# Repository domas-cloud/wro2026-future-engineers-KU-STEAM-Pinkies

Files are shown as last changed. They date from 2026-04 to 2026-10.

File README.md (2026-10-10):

# KU STEAM Pinkies: WRO 2026 Future Engineers

We are **KU STEAM Pinkies** from Klaipėda University STEAM Centre. For WRO 2026 Future Engineers, we built a compact rear-wheel-drive, front-wheel-steer robot with an ESP32, a BNO085 heading sensor, three VL53L1X distance sensors and Pixy2 vision.

We gave each subsystem one job. If hardware added wiring, latency or failure points without giving us useful information, we left it out.

## Team

- **Domas Lukas (left)**
- **Jonas Danisevičius(right)**
- **Marius Plečkaitis(center)**

<p align="center">
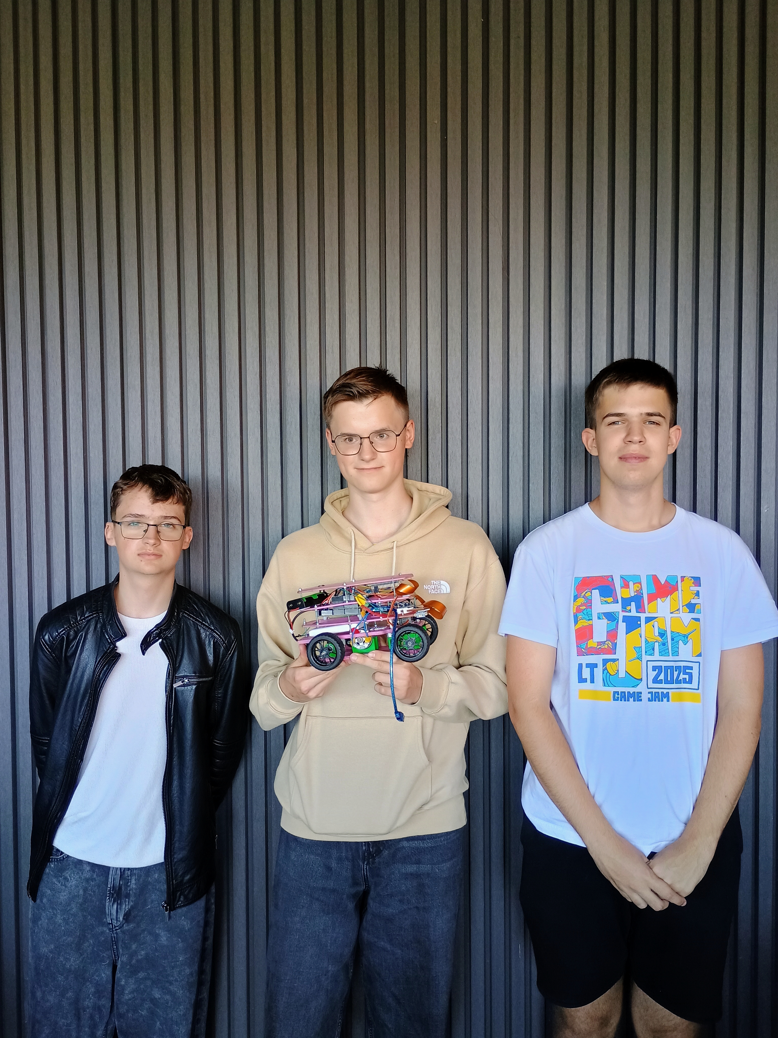
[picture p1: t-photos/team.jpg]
KU STEAM Pinkies team
  
</p>

## Competition videos

- **Open Challenge:** https://youtu.be/wYDWJLPF3cQ
- **Obstacle Challenge:** https://youtu.be/kq5EeDzJqs0

## Contents

- [Final robot](#final-robot)
- [Mechanical design](#1-mechanical-design)
- [Electronics, power and sensors](#2-electronics-power-and-sensors)
- [Software architecture](#3-software-architecture)
- [Engineering decisions and system development](#4-engineering-decisions-and-system-development)
- [Testing and tuning](#5-testing-and-tuning)
- [Robot evolution](#6-robot-evolution)
- [Bill of materials and sourcing](#7-bill-of-materials-and-sourcing)
- [Rebuilding the robot](#8-rebuilding-the-robot)
- [Repository layout](#9-repository-layout)
- [Versioning and verification record](#10-versioning-and-verification-record)
---

# Final robot

The final competition robot has a **black custom PCB and white rear wheels**.

<table>
<tr>
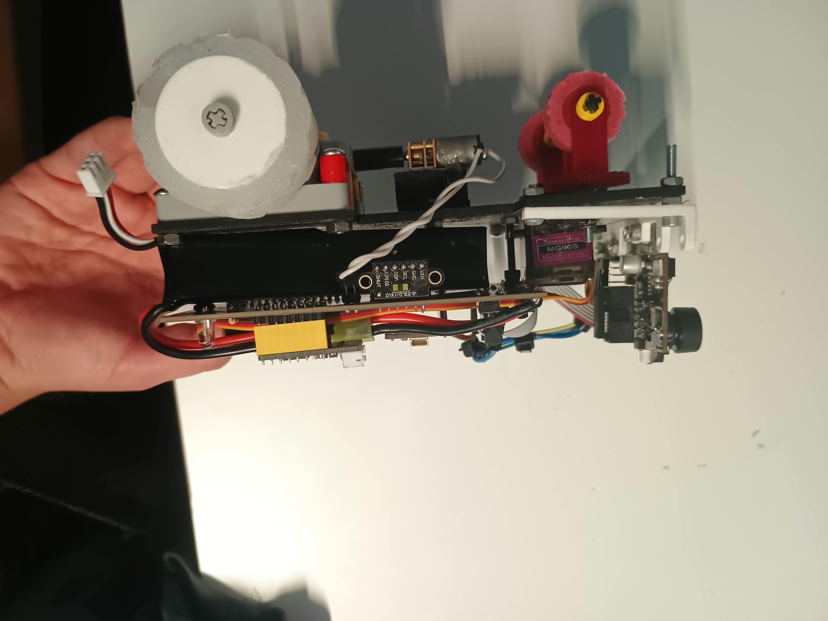
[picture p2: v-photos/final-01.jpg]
<td align="center"><br><b>Final robot, right side</b></td>
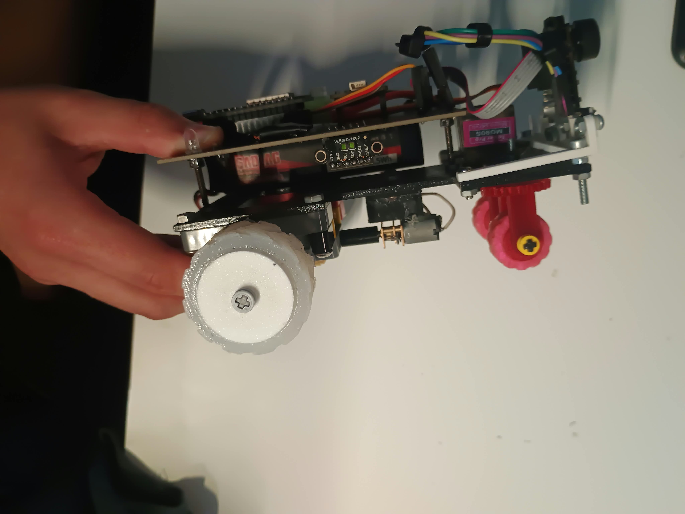
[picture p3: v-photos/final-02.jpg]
<td align="center"><br><b>Final robot, left side</b></td>
</tr>
<tr>
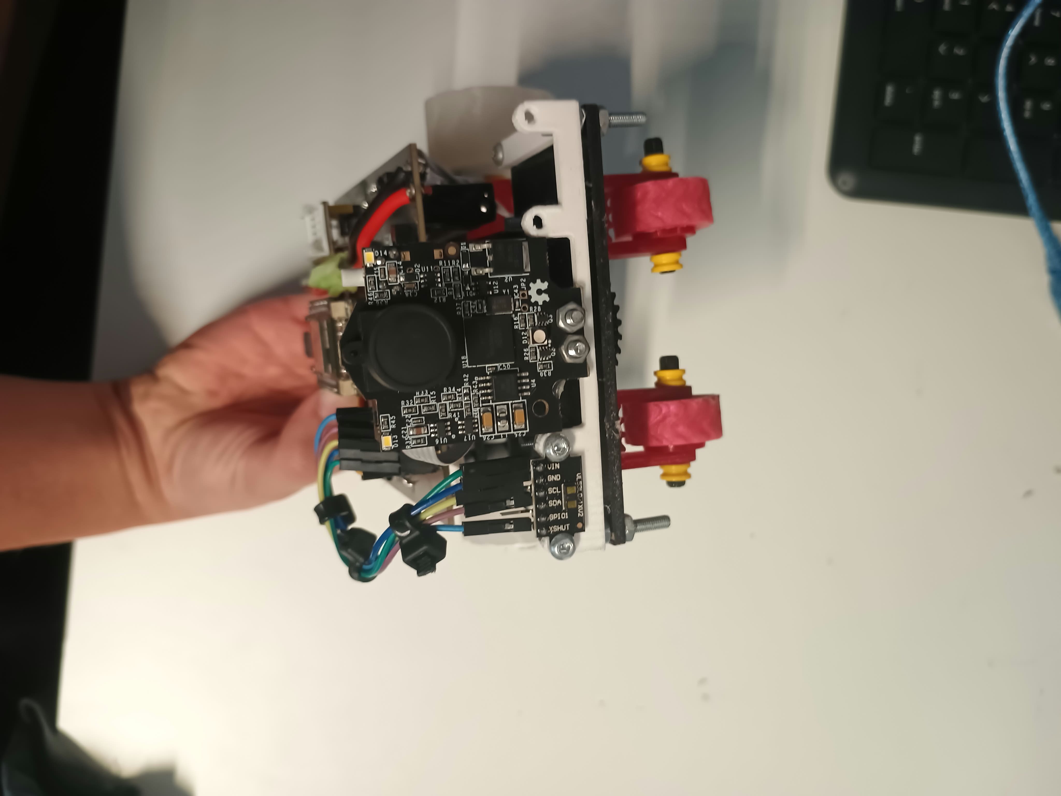
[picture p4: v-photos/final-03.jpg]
<td align="center"><br><b>Final robot, front</b></td>
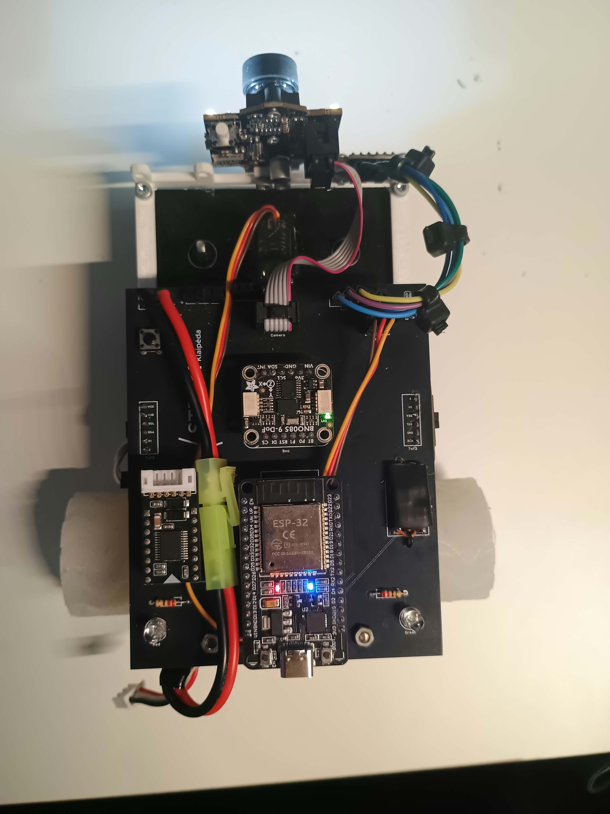
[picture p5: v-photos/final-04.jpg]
<td align="center"><br><b>Final robot, top</b></td>
</tr>
<tr>
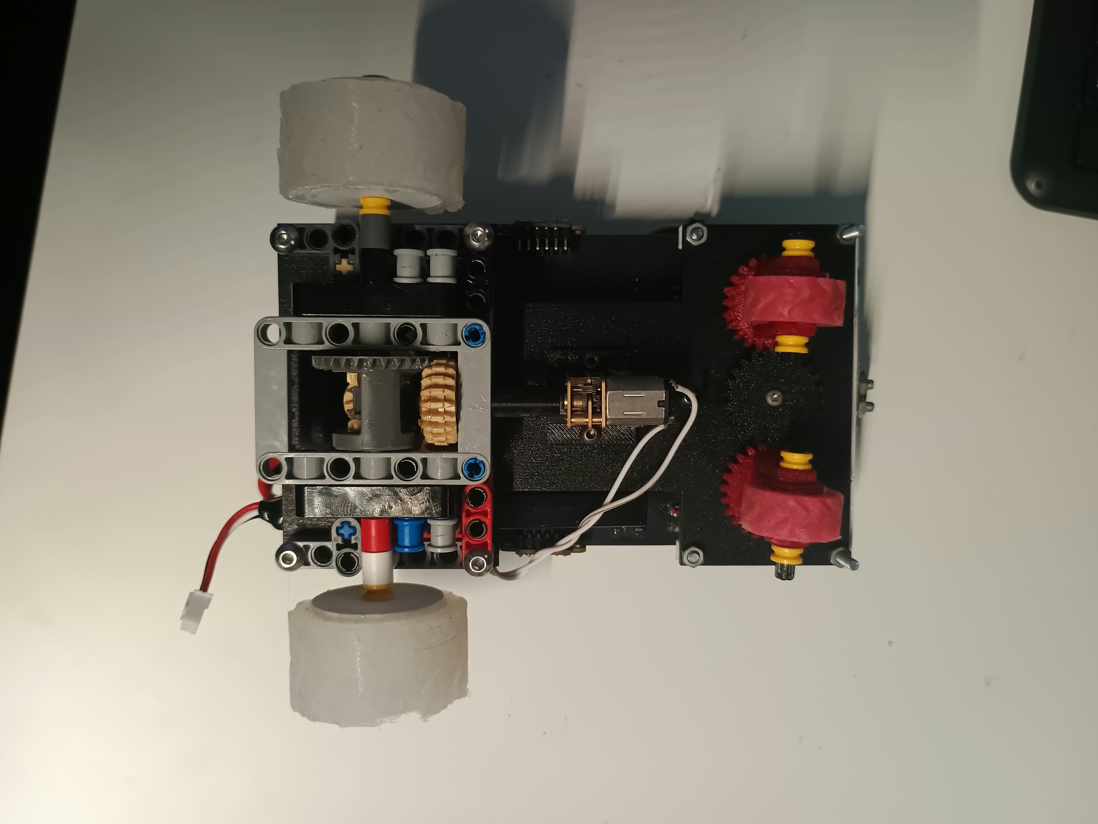
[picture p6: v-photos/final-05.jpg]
<td align="center" colspan="2"><br><b>Final robot, bottom</b></td>
</tr>
</table>

| Subsystem | Final version |
|---|---|
| Controller | ESP32-WROOM-32, 30-pin DevKit V1 form factor |
| Heading | BNO085 |
| Range sensing | 3 × VL53L1X, Long mode |
| Vision | Pixy2 / Pixy2.1 |
| Drive | rear-wheel drive |
| Motor | N20, 6 V, nominal 600 rpm |
| Transmission | LEGO-compatible gearing + LEGO differential |
| Steering | front-wheel steering, positional MG90S |
| Battery | 2S LiPo, 7.4 V, 2500 mAh, 30C |
| 5 V regulator | Matek Micro BEC 6S, 6–30 V input, 5 V/9 V adjustable, used at 5 V |
| Electronics | custom PCB |
| Mass | 332.4 g |
| Approx. overall size | 165 × 145 × 70 mm |

---

# 1. Mechanical design

## 1.1 Layout

We chose **rear-wheel drive** and **front-wheel steering**. That leaves the rear axle to provide traction and the front mechanism to steer. The layout also simplified the control model and left room in the centre of the chassis for the battery, PCB and sensors.

We kept the car compact to leave more room around corners and obstacles and reduce the steering correction needed after a turn.

## 1.2 Drivetrain

```text
N20 geared motor
      ↓
shaft adapter
      ↓
LEGO-compatible gear stage
      ↓
LEGO differential
      ↓
rear wheels
```

The nominal motor speed is 600 rpm. With the final effective reduction of about 1.50:1:

```text
wheel_rpm = 600 / 1.50 = 400 rpm
wheel circumference = π × 0.054 = 0.1696 m
ideal geometric speed = 400 × 0.1696 / 60 ≈ 1.13 m/s
```

The **0.08 N·m motor-torque value comes from the official motor specification**. The **80% drivetrain efficiency is an engineering assumption** used for the design calculation rather than a measured efficiency value:

```text
wheel torque ≈ 0.08 × 1.50 × 0.80 = 0.096 N·m
tractive force ≈ 0.096 / 0.027 ≈ 3.6 N
```

The drivetrain model was used to select the final gearing before integration. We balanced wheel speed against the torque reserve needed for acceleration, steering drag and repeated corner exits. More reduction increases wheel torque but lowers lap speed, while less reduction increases speed at the cost of control margin. The final 1.50:1 ratio gives a compact drivetrain with enough calculated tractive force for the 332.4 g vehicle while keeping the target wheel speed within the controller's useful operating range.

The N20 motor was selected because its compact geared form factor fits the rear-drive layout, aligns cleanly with the LEGO-compatible transmission and provides the required combination of speed and torque without adding another transmission stage.

## 1.3 Differential iteration

<table>
<tr><td align="center"><b>Earlier metal differential</b></td><td align="center"><b>Final LEGO differential</b></td></tr>
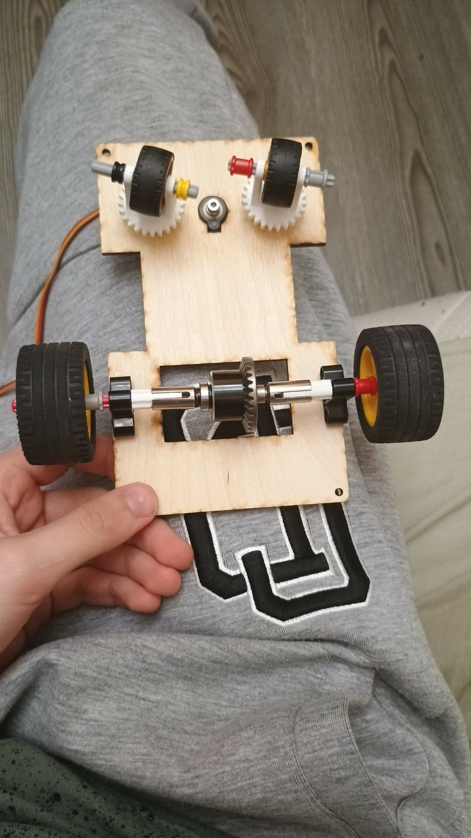
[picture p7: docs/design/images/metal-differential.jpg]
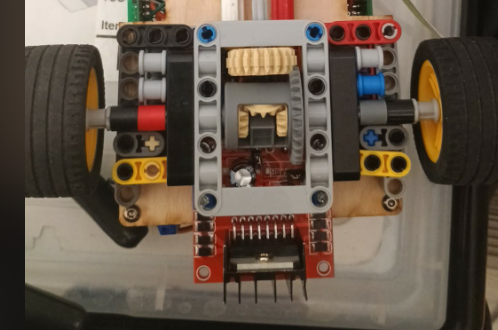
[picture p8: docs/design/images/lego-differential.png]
<tr><td></td><td></td></tr>
</table>

We kept the LEGO differential because it fits the rest of the LEGO-compatible axle and gearing directly, uses fewer custom couplings and is easier to replace during competition. It also allows the two rear wheels to rotate at different speeds in a corner.

## 1.4 Steering iteration

<table>
<tr><td align="center"><b>Earlier steering</b></td><td align="center"><b>Final steering</b></td></tr>
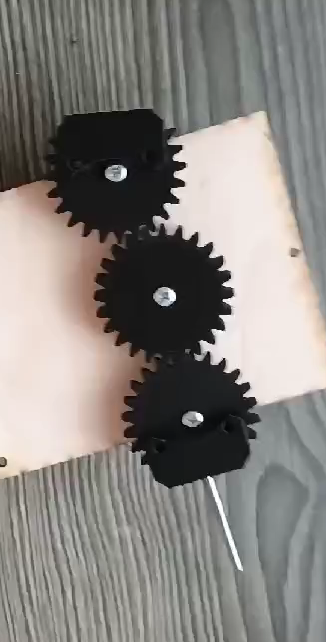
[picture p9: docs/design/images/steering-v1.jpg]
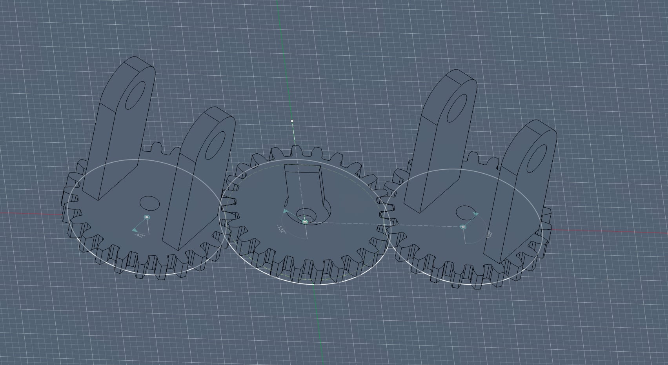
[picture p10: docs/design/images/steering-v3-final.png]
<tr><td></td><td></td></tr>
</table>

The final steering uses a positional MG90S servo. We chose this servo because the steering mechanism needs repeatable absolute positioning in a compact package, and its form factor integrates directly with the front linkage. We centre the linkage mechanically before fixing the servo horn. Firmware limits the servo command from **60° to 120°**, with **88°** as straight ahead. The final linkage is approximately **1:1 in angular movement around the centre position**, so the controller endpoints correspond approximately to **−28° and +32° of wheel steering relative to the 88° straight position**. These endpoint angles are derived from the linkage relationship and firmware commands; they are not separate protractor measurements. The limits keep the linkage inside the mechanically useful steering range and improve repeatability between runs.

The steering redesign reduced the observed space needed for a 90° turn from about **46 cm to 39 cm**, supporting the final compact linkage and steering-range choice.

## 1.5 CAD and base fabrication

The final custom parts are in `models/`:

| Current file in `models/` | Earlier name in Git history | Identification / verification note |
|---|---|---|
| `Front.stl` | unchanged | front-assembly geometry |
| `Front_wheel_gear.stl` | `Body1.stl` | formerly documented as body/structural geometry |
| `Front_wheel.stl` | `motor-shaft-spacer.stl` | formerly documented as motor-shaft spacer |
| `Rear_wheel_mold.stl` | `lego-mold-su-x.stl` | formerly documented as LEGO-interface mould/part |
| `Front_wheel_gear(1).stl` | `steering-column-housing-short.stl` | formerly documented as steering-column housing |
| `middle_gear_steering.stl` | `steering-gear-cover-disc.stl` | formerly documented as steering gear-cover disc |
| `Front_wheel_mold(1).stl` | `steering-gear-hub.stl` | formerly documented as steering-gear hub |
| `Front_wheel_mold.stl` | `steering-gear-plate.stl` | formerly documented as steering-gear plate |
| `Motor_adapter.stl` | `steering-pin-adapter.stl` | formerly documented as steering-pin adapter |
| `case.ai` | unchanged | 2D plywood/base cutting vector |

**File identity note:** These are the actual names present in the checked-in final CAD package. The previous names and descriptions come from the README and Git rename history, not from newly verified CAD assembly constraints. Some newer filenames do not match the earlier descriptions; identify installation positions by inspecting the STL geometry alongside the final robot photos. The former `ratas-su-x.stl` file was deleted and is **not** required for this revision. Do not follow older file lists or silently substitute a missing model.

`models/case.ai` is the base fabrication file. Its main rectangular path is approximately **90 × 150 mm** when imported at the original scale. That number is only a scale check; holes, slots and curves must be taken from the vector itself.

Mechanical build order:

1. cut `models/case.ai` at 1:1 scale;
2. print the STL parts without rescaling;
3. mount the N20 motor and motor-shaft interface;
4. assemble the LEGO-compatible gear stage and rear differential;
5. install the rear wheels and confirm both sides rotate freely;
6. assemble the front steering parts and MG90S;
7. centre the steering mechanically;
8. check the full range from 60° to 120° for binding;
9. mount the electronics stack and compare the result with the final photos above.

Standard LEGO Technic shafts and gears, along with ordinary fasteners, are not performance-tuned. Replace them only with parts that keep the shaft, hole and mounting geometry shown in the CAD and final assembly.

---

# 2. Electronics, power and sensors

## 2.1 Power architecture

The final battery is **2S LiPo, 7.4 V, 2500 mAh, 30C**.

```text
2S LiPo (7.4 V)
  |
  +--> custom PCB --> motor driver --> N20 motor
  |
  +--> Matek Micro BEC 6S (set to 5 V) --> 5VLINE --> ESP32 / BNO085 / VL53L1X / Pixy2 / MG90S
```

Battery energy:

```text
E = 7.4 V × 2.5 Ah = 18.5 Wh
```

### Current budget used during design

| Load | Normal | Short peak | Main concern |
|---|---:|---:|---|
| ESP32 | ~160 mA | ~240 mA | logic stability |
| BNO085 | ~15 mA | ~20 mA | heading stability |
| 3 × VL53L1X | ~75 mA total | ~120 mA total | ranging / I2C stability |
| Pixy2 | ~140 mA | ~200 mA | camera processing |
| MG90S | ~200–300 mA | ~750 mA | steering peak/stall |
| N20 motor | ~350 mA | ~1.3 A | acceleration/stall |
| whole robot | ~0.9–1.2 A | ~1.8–2.2 A coincident design peak; ~2.63 A if every listed individual peak is summed simultaneously | regulator and connector voltage drop |

The PCB netlist shows the 7.4 V battery rail feeding the **Matek Micro BEC 6S**, configured for **5 V**, whose output is the board's `5VLINE`. The regulator is specified for a **6–30 V input**, **5 V or 9 V adjustable output (5 V default)**, **1.5 A continuous load**, and **2.5 A maximum for 5 s/minute**. It also specifies over-current protection, thermal shutdown and short-circuit tolerance. Product reference: https://www.rcdalys.lt/detales/0/27234/MATEK-MICRO-BEC-6S-6-30V-5V9V-ADJUSTABLE-3PCS

The 5 V branch supplies the ESP32, BNO085, three VL53L1X modules, Pixy2 and MG90S. Using the component peak values in the table above, the listed 5 V loads sum to approximately **1.33 A**, below the BEC's **1.5 A continuous** rating. The N20 motor is supplied through the separate battery/motor-driver path, so its current is not part of the BEC load. The individual peak figures are component-level design values; the whole-robot 1.8–2.2 A figure is the expected coincident operating peak because all listed component maxima do not normally occur at exactly the same instant.

## 2.2 Custom PCB

<table>
<tr><td align="center"><b>PCB layout</b></td><td align="center"><b>PCB routing</b></td></tr>
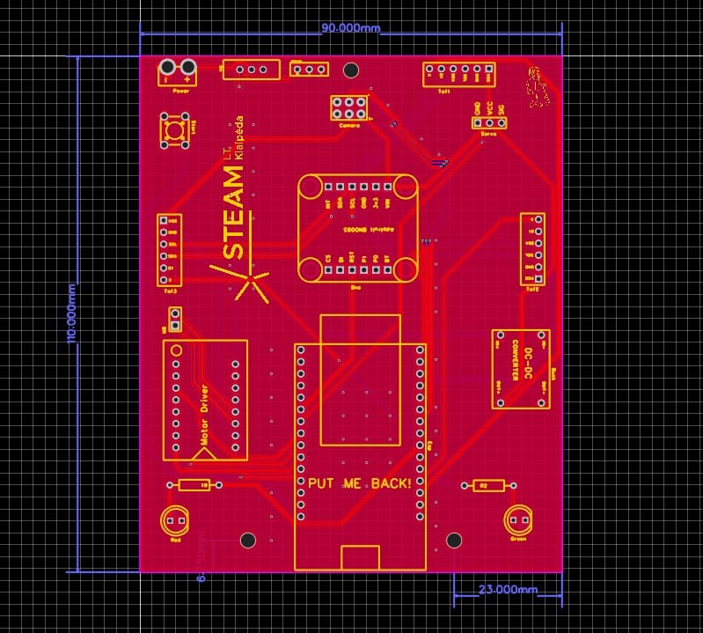
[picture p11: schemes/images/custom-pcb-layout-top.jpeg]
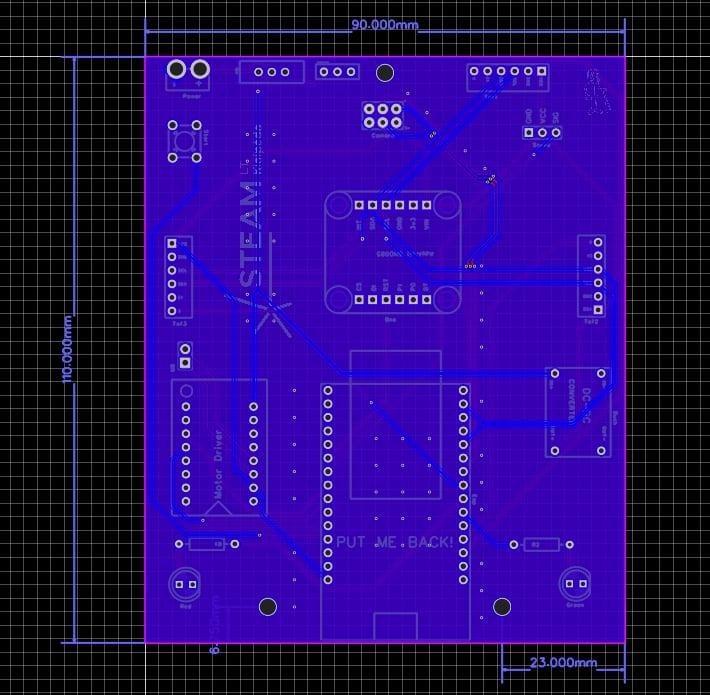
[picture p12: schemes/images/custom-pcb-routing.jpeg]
<tr><td></td><td></td></tr>
</table>

### Wiring and sensor-bus diagrams

<p align="center">
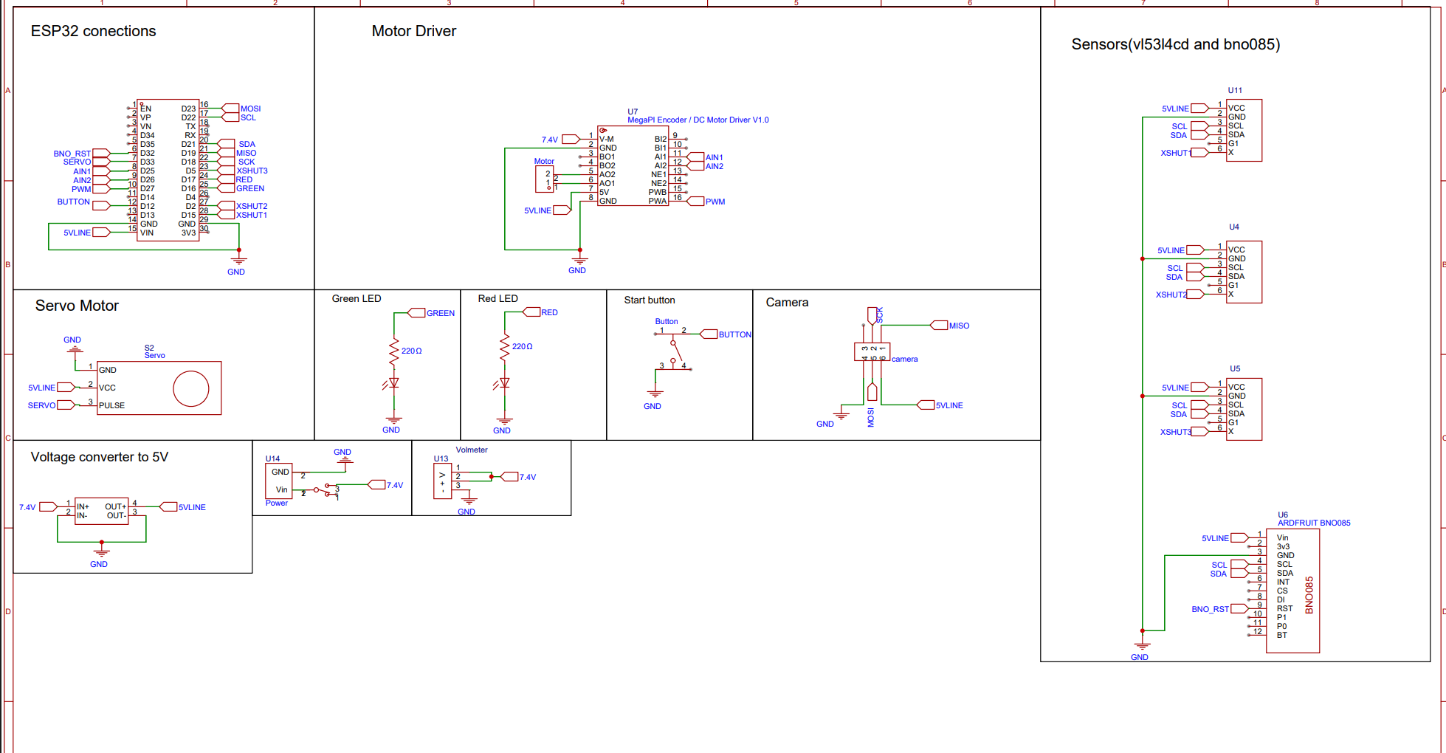
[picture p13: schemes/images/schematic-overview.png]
Robot electrical wiring and power architecture
  
</p>

<p align="center"><strong>Electrical overview.</strong> The diagram shows the battery, regulated logic supply, ESP32, motor driver, steering servo and sensor connections used on the final robot.</p>

**Sensor-bus detail (functional connection map):**

```text
ESP32 I2C SDA/SCL  ---+--- BNO085
                      +--- Front VL53L1X (XSHUT GPIO15, address 0x30)
                      +--- Left  VL53L1X (XSHUT GPIO5,  address 0x31)
                      +--- Right VL53L1X (XSHUT GPIO18, address 0x32)
ESP32 SPI (MOSI/MISO/SCK) --- Pixy2 (separate camera interface)
```

All I2C sensors share the bus; each ToF XSHUT is controlled separately to resolve the sensors' identical factory addresses. The electrical image above and the PCB files in `schemes/` are the physical wiring references. This connection map is functional rather than a substitute for the PCB netlist.

The electrical folder contains:

- `schemes/Wro_customPCBs.pdf`
- `schemes/images/schematic-overview.png`
- complete top/bottom copper, solder-mask and silkscreen Gerbers
- board outline and mechanical/document layers
- plated, non-plated and via drill files
- flying-probe test data

The Gerber and drill files are for manufacturing the final PCB revision.

## 2.3 Pin and sensor identity

| Function | ESP32 pin / bus |
|---|---|
| Start button | GPIO14 |
| Motor enable / PWM | GPIO32 |
| Motor input 1 | GPIO26 |
| Motor input 2 | GPIO25 |
| Steering servo | GPIO33 |
| Front VL53L1X XSHUT | GPIO15 |
| Left VL53L1X XSHUT | GPIO5 |
| Right VL53L1X XSHUT | GPIO18 |
| BNO085 | I2C |
| 3 × VL53L1X | shared I2C, separate XSHUT |
| Pixy2 | SPI on custom PCB (MOSI / MISO / SCK) |

All three ToF modules share the same factory I2C address. Firmware enables them one at a time and assigns each a different runtime address:

| Sensor | XSHUT | Runtime address |
|---|---:|---:|
| Front | GPIO15 | `0x30` |
| Left | GPIO5 | `0x31` |
| Right | GPIO18 | `0x32` |

## 2.4 Sensor placement and track geometry

The **front VL53L1X** faces forward on the robot **centreline**, beside the **Pixy2** camera. It measures forward clearance and helps detect a corner; Pixy2 independently reports the position of coloured obstacles. The **left and right VL53L1X** modules are installed directly in the dedicated ToF positions provided by the custom PCB, at its lateral sides, and measure the corresponding side clearances for wall correction. Their placement is therefore fixed by the checked-in PCB layout rather than by an arbitrary hand-measured mounting offset. The chassis-mounted **BNO085** provides heading, so range and orientation feedback come from separate sensors.

<table>
<tr>
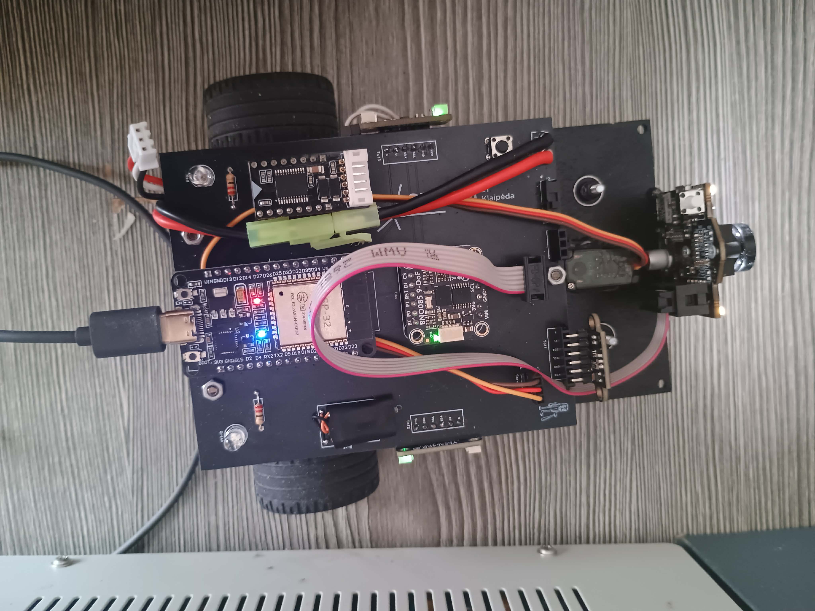
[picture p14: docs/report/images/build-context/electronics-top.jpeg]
Top view of the assembled electronics and sensor locations
<td align="center"><br><strong>Installed sensor positions.</strong> Left and right VL53L1X modules sit at the PCB side edges; the front VL53L1X is beside Pixy2.</td>
<td align="center">Dimensioned top view of the custom PCB<br><strong>PCB footprint.</strong> The drawing marks the board as 90 × 100 mm.</td>
</tr>
</table>

The robot's documented overall dimensions are approximately **165 × 145 × 70 mm**.

### Projection onto the WRO corridor

The [WRO 2026 Future Engineers rules](https://wro.hr/wp-content/uploads/2026/01/WRO-2026-Future-Engineers-Self-Driving-Cars-General-Rules.pdf) specify nominal corridor widths of **600 mm or 1000 mm** for Open Challenge, and **1000 mm** for Obstacle Challenge. The Open Challenge width may vary by ±100 mm at the International Final; Obstacle Challenge specifies ±10 mm.

For the corridor model, the **90 mm PCB dimension runs across the robot**, with the left and right ToF modules positioned at the two lateral PCB edges. The centred-reference calculation below shows how that sensor spacing relates to the nominal WRO corridor widths and to the documented 145 mm vehicle width.

| WRO section | Nominal corridor width | Side sensor centre to nearest wall, centred | Robot body side to wall, centred |
|---|---:|---:|---:|
| Open Challenge, narrow corridor | 600 mm | ≈255 mm | ≈227.5 mm |
| Open Challenge, wide corridor | 1000 mm | ≈455 mm | ≈427.5 mm |
| Obstacle Challenge | 1000 mm | ≈455 mm | ≈427.5 mm |

Calculation: `sensor-to-wall = (corridor width − 90 mm) / 2`; body clearance uses the documented 145 mm vehicle width: `(corridor width − 145 mm) / 2`. Firmware uses `ROBOT_WIDTH = 150 mm` as its rounded control model.

```text
Plan view — schematic, not to scale

600 mm corridor:
LEFT WALL │← ≈255 mm →│ ● Left ToF ── ≈90 mm ── Right ToF ● │← ≈255 mm →│ RIGHT WALL

1000 mm corridor:
LEFT WALL │← ≈455 mm →│ ● Left ToF ── ≈90 mm ── Right ToF ● │← ≈455 mm →│ RIGHT WALL

Robot layout (body width ≈145 mm):
                         FRONT / direction of travel ↑
+----------------------------------------------+
| Front VL53L1X beside Pixy2 camera            |
| Left ToF   [PCB 90 × 100 mm]   Right ToF     |
+----------------------------------------------+
```

The firmware's `TARGET_DISTANCE=300 mm` is a side-wall setpoint while the current section width is unknown; in the Obstacle Challenge build, section width is not learned, so normal wall following uses that 300 mm target. At the nominal centred geometry, this is 45 mm farther from the selected wall than the 600 mm corridor reading (≈255 mm), and 155 mm closer to the selected wall than the 1000 mm corridor reading (≈455 mm). This comparison shows why the controller's 300 mm wall target provides a practical starting point across the two Open Challenge corridor widths while leaving the final correction to the live side-distance measurements.

## 2.5 Sensor architecture changes

### MPU6050 → BNO085

The earlier MPU6050 setup showed noticeable yaw drift during repeated turns. Because heading error directly becomes steering error, we replaced it with BNO085 and used the IMU as the dedicated chassis-heading reference.

### Five range sensors → three VL53L1X + BNO085

With the BNO085 handling heading, we only needed three range measurements: front, left and right. We removed the other range modules and their wiring.

### VL53L4CD → VL53L1X Long mode

The side controller needs wall readings before the car gets close to a wall. VL53L1X Long mode provided a larger useful range, so we used it for all three distance sensors.

### Raspberry Pi camera chain → Pixy2 directly to ESP32 over SPI

The final PCB connects Pixy2 directly to the ESP32 using the SPI data and clock nets `MOSI`, `MISO` and `SCK`. This removed the Raspberry Pi processing stage and its inter-processor communication link, reducing wiring and communication stages.

## 2.6 Calibration

**ToF identity and direction**

1. Put a flat target close to the left module only and check that the left channel changes.
2. Repeat for the right module.
3. Check the front sensor against a target placed on the centreline.
4. Test several known distances and record mean reading, spread and invalid samples.
5. Make sure no wheel or chassis part clips a sensor beam.

**BNO085**

1. Point the car along a known straight reference.
2. Record yaw.
3. Rotate the chassis about 90° and confirm the expected sign/direction.
4. Cross the 0°/360° boundary to check heading wrapping.

**Pixy2**

1. Open **PixyMon** and train the colour signatures on the actual obstacle cubes used for testing.
2. Train/check each cube individually rather than relying on one generic colour sample.
3. Repeat the signature check under different lighting conditions so the stored signatures remain usable when ambient illumination changes.
4. Place a trained obstacle near image centre and confirm that Pixy2 reports the expected signature.
5. Move it left and right and verify the reported X coordinate changes in the expected direction.
6. Check that the front structure does not block the useful image area.

The camera calibration is therefore based on PixyMon's trained colour signatures rather than fixed RGB/HSV values in the ESP32 firmware.

---

# 3. Software architecture

The final firmware is in `src/` and is built with PlatformIO.

Two build environments use the same source code:

```bash
platformio run -d src -e open_challenge
platformio run -d src -e obstacle_challenge
```

- `open_challenge` uses `WRO_CHALLENGE_MODE=0`
- `obstacle_challenge` uses `WRO_CHALLENGE_MODE=1`

`src/include/CompetitionMode.h` validates the build-time value, so challenge mode is not changed by editing `main.cpp`.

Build verification is **manual**. The repository intentionally does not include GitHub Actions CI or a `scripts/` verification directory. The same two commands above are the documented reproducible build entry points.

## 3.1 Modules

| Module | Responsibility |
|---|---|
| `src/src/main.cpp` | driving behaviour and state transitions |
| `Engine` | DC motor direction and PWM |
| `Compass` | BNO085 startup and yaw |
| `Distance_Sensor` | VL53L1X startup, address assignment and ranging |
| Pixy2 interface | colour connected-component acquisition |
| `Lights` | visible robot state |
| `CompetitionMode.h` | Open/Obstacle build selection |

## 3.2 State machine

The controller follows a state machine:

```text
WAIT_FOR_START
      |
      | start button
      v
NORMAL_DRIVING
   |       |
   |       +-- corner detected --> TURNING --------+
   |                                               |
   +-- obstacle detected --> OBSTACLE_AVOIDANCE    |
                              |                     |
                              | obstacle disappears |
                              v                     |
                         OBSTACLE_RECOVERY ----------+
                              |
                              | recovery timer ends
                              v
                        NORMAL_DRIVING

12 corners / 3 laps + stable finish condition --> FINISHED
sensor-start failure ---------------------------> ERROR
```

The same control flow is shown below as a diagram for quicker review:

```mermaid
flowchart TD
    A[WAIT_FOR_START] -->|start button| B[NORMAL_DRIVING]
    B -->|corner detected| C[TURNING]
    C --> B
    B -->|obstacle detected| D[OBSTACLE_AVOIDANCE]
    D -->|obstacle no longer detected| E[OBSTACLE_RECOVERY]
    E -->|recovery interval completed| B
    B -->|12 corners / 3 laps + stable finish| F[FINISHED]
    A -->|essential sensor startup failure| G[ERROR]
```

### What each state does

- **WAIT_FOR_START** keeps the motor stopped until the team starts a run.
- **NORMAL_DRIVING** uses heading and wall control.
- **TURNING** handles a corner and updates the target heading by about 90° after the turn condition is met.
- **OBSTACLE_AVOIDANCE** gives Pixy2 steering priority while an obstacle block is present.
- **OBSTACLE_RECOVERY** keeps wall following from taking over while the car is still angled after passing an obstacle.
- **FINISHED** keeps the robot stopped after the coded three-lap finish condition. It does not execute parallel parking.
- **ERROR** stops the run if an essential sensor fails during startup.

## 3.3 Heading and wall control

Heading error is wrapped to the shortest direction:

```text
heading_error = target_heading - yaw
if heading_error > 180:  heading_error -= 360
if heading_error < -180: heading_error += 360
```

Heading error sets the base steering correction. A derivative damping term is included to reduce abrupt steering changes and improve stability as the robot converges back toward its target heading.

Wall correction uses the outside wall:

```text
wall_error = measured_outer_wall_distance - target_wall_distance
```

Clockwise runs use the left outer wall, and counter-clockwise runs use the right. The controller accepts a range reading only when its status and the combined left and right distances are plausible.

The steering command is conceptually:

```text
straight centre
+ heading correction
+ wall-distance correction
+ derivative damping
+ Pixy2 correction when avoiding an obstacle
```

Servo output is clamped to the mechanical range.

## 3.4 Corner strategy

When the front ToF detects a corner, the controller enters `TURNING`. If the driving direction is not set yet, it locks one in, steers to the turn limit and waits for the sensor to show that the car has cleared the corner. It then updates the target heading by about 90° and returns to `NORMAL_DRIVING`.

The front ToF tells the controller when to turn; BNO085 provides the heading the car should recover to.

## 3.5 Obstacle strategy

In `obstacle_challenge`, Pixy2 CCC blocks go straight to the ESP32. The controller filters detections by height so tiny or oversized blocks do not trigger steering.

Among the remaining blocks, the controller selects the block with the largest image-Y coordinate as a **camera-image proximity heuristic** (not a direct physical-distance measurement). The team trained **Pixy2 signature 1 for the green pillar** and **signature 2 for the red pillar** in PixyMon. Under the WRO rules, green must be passed on the left and red on the right. The code uses the signature-dependent horizontal image target to generate a steering correction; the sign of the resulting physical turn depends on the fitted steering mechanism and camera orientation, which must be verified on the track.

The checked-in `main.cpp` now accepts only Pixy2 **signature 1 (green)** and **signature 2 (red)** when selecting an obstacle block. Blocks bearing any other signature are discarded rather than being treated as red. This is a code-level robustness change; the physical behaviour with reflective objects, lighting variation and unexpected signatures still needs a recorded track test.

Current obstacle tuning constants:

| Parameter | Value |
|---|---:|
| Minimum block height | 8 |
| Maximum block height | 70 |
| Signature 1 — green offset | -105 |
| Signature 2 — red offset | 55 |
| Pixy steering gain | 0.32 |
| Recovery time | 450 ms |

When the obstacle disappears, the controller waits 450 ms in `OBSTACLE_RECOVERY`, then resumes wall control.

**Current competition limitation — parking:** The team's present robot does **not** implement autonomous parallel parking. The `FINISHED` state in `src/src/main.cpp` is a three-lap stop condition, **not** a parking manoeuvre. Therefore, demonstrations and performance summaries here describe driving and obstacle avoidance, not a successfully completed WRO Obstacle Challenge including parking. Parking remains an unimplemented task under the 2026 rules.

## 3.6 Controller constants

| Constant | Value |
|---|---:|
| `ROBOT_WIDTH` | 150 mm controller model |
| `TARGET_DISTANCE` | 300 mm |
| `WIDTH_THRESHOLD` | 150 mm |
| `MIN_ANGLE` | 60° |
| `MAX_ANGLE` | 120° |
| `STRAIGHT_ANGLE` | 88° |
| `Kp` | 0.09 |
| `Kg` | 0.95 |
| `Kd` | 0.05 |

## 3.7 Controller tuning and boundaries

The team iterated controller coefficients and corner behaviour during development. The final constants below are taken directly from `src/src/main.cpp`; no intermediate coefficient history is available for a numeric before/after comparison.

| Control element | Current code | Engineering purpose / check |
|---|---|---|
| Heading | `angle = Kg * heading`, `Kg = 0.95` | Bring the robot back to the BNO085 target heading; verify both driving directions |
| Wall position | `Kp = 0.09` applied to outer-wall distance error | Correct lateral displacement only when distance/geometry gates pass |
| Damping | `Kd = 0.05` applied to an error-difference term over elapsed time | Moderate abrupt steering changes; review overshoot on corner exit |
| Corner detection | Valid front ToF reading, a front-clearance threshold and combined side width ≥ 900 mm | Distinguish corner entry from normal wall following |
| Corner steering | Servo limited to 60° or 120° during the turn | Keep the command inside the chosen mechanical travel |
| Corner counting | One increment after the front-distance turn-exit condition | Track the required 12 corners over three laps |
| Normal stop | At least 12 counted corners, wall-distance error under 50 mm and heading error within 5° for 2 seconds | Avoid declaring a finish on a single instantaneous reading |

The firmware handles heading wrap across 0°/360°, stops on essential ToF/BNO085 **initialisation** failures, ignores implausible readings for specified wall-control paths and uses a 450 ms obstacle-recovery state. These are code-level mechanisms, not claims that every physical failure has been eliminated.

**Cases to test explicitly:** uncertain colour classification; an unrelated Pixy2 signature; loss of valid ToF readings during a corner; heading events unavailable after start; unexpected stopping or restarting; and return to the finish area after the twelfth corner. The corner-exit `while` loop now has an independent **5000 ms watchdog**. If it expires, the firmware stops the motor and enters `ERROR` rather than driving indefinitely. This is a conservative code fail-safe, **not a measured or validated corner duration**; verify that normal corners finish comfortably before the limit on the physical track. The `FINISHED` state remains a three-lap stop, **not** parallel parking.

## 3.8 Robustness and safeguards

The final control architecture includes several safeguards for stable competition operation:

- Separate XSHUT lines allow the three ToF sensors to receive unique runtime I2C addresses during startup.
- Essential distance and heading sensors are validated before motion begins.
- Front ToF validity is checked at corner entry, and outer-wall readings are subject to distance/geometry gates during wall correction; some other paths, including the combined side-width condition, do not separately reject all invalid readings.
- Heading error is normalised to ±180° across the 0°/360° boundary.
- Pixy2 detections are filtered by block size **and an explicit allow-list (signatures 1 and 2)** before obstacle steering is applied.
- A 5000 ms corner-exit watchdog stops the drive and enters `ERROR` if the exit condition does not occur; physical timeout validation is pending.
- Servo commands are clamped to the tested mechanical steering range.
- A dedicated recovery state smooths the transition from obstacle avoidance back to wall following.
- The documented current budget identifies the regulator's design margin; a dated under-load voltage/current log would be stronger physical verification.

---

# 4. Engineering decisions and system development

We designed around chassis size, corner clearance, steering geometry, drivetrain alignment, power stability, I2C addressing, camera view and loop latency. The robot also had to be repairable and quick to debug at a competition.

| Earlier approach | Final approach | Why we changed it |
|---|---|---|
| larger packaging | compact chassis | more clearance and simpler layout |
| metal/custom differential interfaces | LEGO differential | easier integration and repair |
| MPU6050 | BNO085 | more useful heading reference after observed drift |
| five range sensors | three VL53L1X + BNO085 | clearer sensor roles and less wiring |
| VL53L4CD side sensing | VL53L1X Long mode | larger useful wall-ranging region |
| Raspberry Pi camera chain | Pixy2 directly to ESP32 over SPI | fewer processors and communication stages |
| prototype wiring | custom PCB | repeatable and compact electrical build |
| earlier Li-ion arrangement | 2S LiPo | compact package with good transient-current reserve |
| earlier steering linkage | revised compact linkage | better centring and less binding |
| implicit behaviour flags | explicit state machine | easier to understand, test and recover between behaviours |

## Risk table

| Failure | Effect | Mitigation |
|---|---|---|
| ToF address collision | no reliable distance data | independent XSHUT + `0x30/0x31/0x32` addresses |
| bad front range | wrong corner trigger | status check and startup validation |
| bad side range | wrong wall correction | range/status/geometry filtering |
| IMU failure | no heading reference | startup check |
| heading wrap | very large false error | ±180° normalisation |
| steering over-travel | binding / heating | mechanical centring + 60°–120° clamp |
| false vision block | wrong passing path | signature 1/2 allow-list, height and image-position filtering; needs physical validation |
| stalled corner-exit reading | indefinite turn / wall collision | 5000 ms watchdog, stop motor and enter ERROR; track validation pending |
| obstacle hand-back too early | oscillation after pass | dedicated recovery state |
| power sag | reset or sensor dropout | current margin + powered load test |
| loose wiring | intermittent fault | custom PCB and fixed connectors |
| firmware/document mismatch | hard-to-reproduce robot | Git history, two fixed PlatformIO environments, manual verification workflow and the README versioning record |

---

# 5. Testing and tuning

## 5.1 Testing approach

The final robot was tuned through repeated mechanical, sensor, control and full-route testing. Consolidated results are stored in [`docs/testing/validation-summary.csv`](docs/testing/validation-summary.csv), while [`docs/testing/raw/run-template.csv`](docs/testing/raw/run-template.csv) provides a consistent format for future run-level validation.

We tuned the robot in this order:

1. free mechanical movement and steering centre;
2. BNO085 direction and heading response;
3. heading gain;
4. derivative damping;
5. wall-distance gain;
6. clockwise and counter-clockwise corners;
7. Pixy2 obstacle pass;
8. obstacle recovery;
9. repeated full-route attempts.

Saved results are in `docs/testing/validation-summary.csv`.

## 5.2 Manual verification and evidence workflow

This repository uses a manual verification workflow rather than GitHub Actions CI:

1. record the Git commit SHA for the revision being tested;
2. run `platformio run -d src -e open_challenge`;
3. run `platformio run -d src -e obstacle_challenge`;
4. perform the sensor calibration checks in section 2.6;
5. perform the final acceptance checks in section 8;
6. for each new physical run, copy `docs/testing/raw/run-template.csv` and record challenge mode, firmware SHA, battery state, changed variable, result and measured outcome;
7. update `docs/testing/validation-summary.csv` with the retained validation results.

The repository versioning and verification record is included in section 10 of this README. The complete repeatable test procedure, measurement definitions and evidence rules are in sections 5.3–5.6 **of this README**.

### Current qualitative performance estimate

The team reports **approximately 8/10 successful Open Challenge driving attempts (~80%)** and **approximately 6/10 successful Obstacle Challenge driving/avoidance attempts (~60%)** with the current robot. These are informal approximate field estimates, **not** ten individually recorded trials with a controlled layout. Their detailed pass/fail definitions, distributions across layouts and firmware SHAs have not been retained. In particular, **the obstacle estimate excludes autonomous parking**, which is not implemented. Consequently, it must not be described as a 60% success rate for completing the entire 2026 Obstacle Challenge.

The engineering development included tuning steering coefficients and corner behaviour. The current coefficient values are listed in section 3.6, and testable tuning questions are described in sections 3.7 and 5.4 of this README.

### Historical test summary and evidence provenance

The figures below reproduce the project's existing historical summary. These are **archived prior estimates, not the current 8/10 and 6/10 estimates** and not independently validated measurements. They are **not** an independently reconstructable run-by-run dataset: the original per-run logs, firmware SHA and exact field layouts for these earlier summaries were not retained. The evidence classes in `docs/testing/validation-summary.csv` distinguish team-reported comparisons, summary observations and retained five-value drift comparisons. The five-value calculations can be checked arithmetically, but the original measurement conditions cannot be independently re-created from the surviving records alone. New quantitative claims should be based on newly logged runs with firmware and layout identifiers.

| Test | Earlier | Updated/final | Notes |
|---|---:|---:|---|
| Straight drift after 2 m | 9 cm | 4 cm | prototype → final comparison, 10 runs |
| Successful 3-lap runs (archived estimate, not current) | 6/10 | 9/10 | Original per-run logs unavailable; not to be used as present success rate |
| Corner overshoot | 14 cm | 6 cm | prototype → final comparison |
| Obstacle recovery | 1.2 s | 0.6 s | prototype → final comparison |
| Matched 3 m drift mean | 10.6 cm | 4.0 cm | five retained values per version |
| Open straight | — | 5/5 | final layout |
| Obstacle slalom | — | 4/5 | final layout |
| Full practice route | — | 4/5 | final layout |
| 90° turning space | ~46 cm | ~39 cm | prototype → final comparison |

For the matched 3 m drift comparison, the retained values are:

```text
earlier: 11, 10, 12, 9, 11 cm  -> mean 10.6 cm
updated:  4,  5,  3, 4,  4 cm  -> mean  4.0 cm
```

That is a 6.6 cm reduction in the retained means, about 62%.

For future physical runs, `docs/testing/raw/run-template.csv` keeps challenge mode, firmware SHA, battery state, changed variable and measured outcome in one consistent format. The two linked YouTube videos at the top provide a visual demonstration of the final robot according to the team; they do not by themselves establish a statistically sampled success rate, nor do they establish successful parallel parking.

## 5.3 Repeatable test setup and traceability

The following procedure is for documenting **future physical testing**. It does not assert that tests were performed after the historical summary above. Estimated results must not be converted into invented per-run measurements.

Before changing firmware or tuning, save the full Git commit SHA and select the correct PlatformIO environment:
- `platformio run -d src -e open_challenge`
- `platformio run -d src -e obstacle_challenge`

Use a copy of `docs/testing/raw/run-template.csv` for each physical test series. Record the date/time, firmware SHA, mode, direction and track layout, battery voltage/state if measured, parameter intentionally changed, outcome, elapsed time, observed errors and any reset or repair. Enter `not measured` when an instrument or reliable visual measurement is unavailable rather than inventing a precision value.

The test layout should record the corridor widths (for Open Challenge), start zone, direction and the positions and signatures of relevant coloured pillars (for Obstacle Challenge). A top-view photo or sketch labelled with the run ID is useful.

## 5.4 Repeatable physical test procedures

### A. Steering and corner tuning

1. Record the deployed values of `Kp`, `Kg`, `Kd`, turn thresholds and 60°/120° steering limits.
2. Check the servo centre and both mechanical end positions with the drive motor disabled.
3. Drive a known straight segment. If measuring drift, identify the reference line, the distance travelled (2 m or 3 m), and the lateral offset at the endpoint in cm.
4. Test clockwise and counter-clockwise 90° corners with identical layout and start speed.
5. For each attempt, note whether the front ToF initiated a turn, whether it exited the turn condition, any wall contact, and any visibly excessive correction.
6. Change only one gain or threshold at a time, keeping a record of the old and new values and of the same test layout. Do not describe an improvement quantitatively unless matched measurements were retained.

### B. Pixy2 signatures and obstacle passing

The team uses signature **1 = green** and signature **2 = red**. WRO 2026 requires green to be passed on the left and red on the right.

1. In PixyMon verify each of the two trained colour signatures under the lighting used for the test.
2. Place the green and red pillar in turn at known track positions. Record each detected signature and whether the physical pass is on the required side.
3. Repeat from the two track directions where the layout permits.
4. Vary one parameter per series: target image offsets (`-105` for signature 1 and `55` for signature 2), block-height filter, steering gain (`0.32`) or recovery period (`450 ms`).
5. Note mistaken signatures, missed detections, contacts, side errors and recovery behaviour. A video link and timestamp should be attached for decisive cases.
6. Present an unrelated/untrained Pixy2 signature during a controlled test. Confirm that it is ignored and does not create an obstacle steering command; record the event and firmware SHA.

### C. Three-lap run, stopping and parking status

1. Record the firmware SHA, track layout and start configuration.
2. Attempt three full laps without touching or adjusting the vehicle after the authorised start.
3. Record laps and counted corners, final stopping behaviour, wall/pillar contacts and whether intervention was required.
4. **Current status:** autonomous parallel parking is **not implemented**. For an Obstacle Challenge driving run, score the three-lap/obstacle portion separately and record parking as `not implemented`, never `success`. If parking is added in a future firmware revision, separately record whether the parking-space boundaries remain untouched and whether the robot finishes inside and parallel. The present `FINISHED` state only implements a stop condition.
5. A success fraction is `successful independently documented runs / all independently documented attempts`. Keep failed attempts in the denominator; do not combine incompatible layouts as if they were identical.

### D. Corner-exit watchdog and failure checks

1. With the drive wheels raised and no wall contact possible, verify that a stuck front-ToF corner-exit condition cannot keep the motor running indefinitely; expected code action is motor stop and `ERROR` after 5000 ms.
2. Repeat normal clockwise and counter-clockwise corners on the actual track, recording entry-to-exit times and whether the watchdog was activated.
3. Treat the fail-safe as **implemented but not physically verified** until these tests are logged; never report test success solely because the code contains the watchdog.

## 5.5 Metric definitions

| Metric | Definition | Source |
|---|---|---|
| Straight-line drift (cm) | Lateral endpoint offset after a stated 2 m or 3 m straight | Tape/ruler and reference line |
| Turn overshoot (cm) | Maximum lateral deviation from the stated intended path after a 90° corner | Marked track / measured video |
| Obstacle pass success | Correct pass side with no disqualifying contact | Video + run sheet |
| Three-lap completion | Three complete laps and separately recorded finish behaviour | Video + run sheet |
| Obstacle recovery (s) | Time from obstacle no longer being detected to normal steering control, using a defined source | Instrumented trace / frame-by-frame video |
| Reset/timeout count | Number of controller resets or uncompleted turn conditions per run | Serial/event notes |
| Supply voltage (V) | Measured 5 V line or battery voltage and specified load state | Multimeter / logger |

Report `n`, exact metric, units, setup and spread/range with any average. When a metric cannot be measured, log the observation qualitatively and leave the numeric field blank or mark it unavailable.

## 5.6 Evidence quality and reporting

1. Source-controlled firmware SHA, raw run record, corresponding video with time markers and a documented layout.
2. Dated test notes with measured values and enough setup information to repeat.
3. Historical team summary and observations, which can illustrate development but are not equivalent to a traceable run series.

Preserve the existing `validation-summary.csv` as a historical summary. Add new physical results with their own source evidence and do not overwrite older values to make the trend look smoother.

The retained historical CSV remains linked as a numerical supporting file, while the result interpretation and the measurement protocol are fully explained in this README. A future physical test may improve the confidence in the reported estimates; documentation alone cannot supply missing measurements.

---

# 6. Robot evolution

We kept older photos to show how the design changed.

## Stage 1: earlier full vehicle

<table>
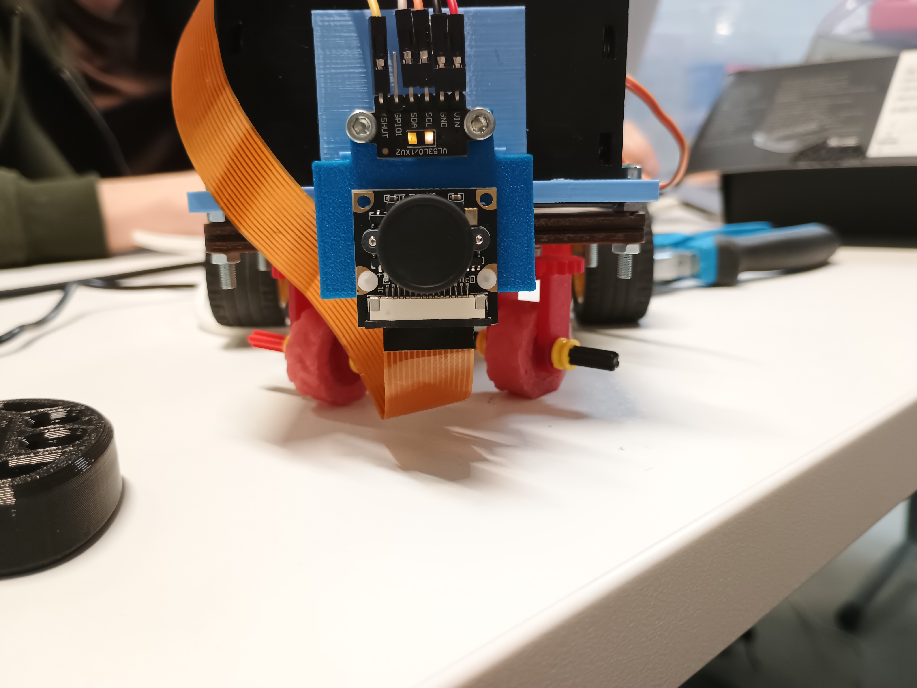
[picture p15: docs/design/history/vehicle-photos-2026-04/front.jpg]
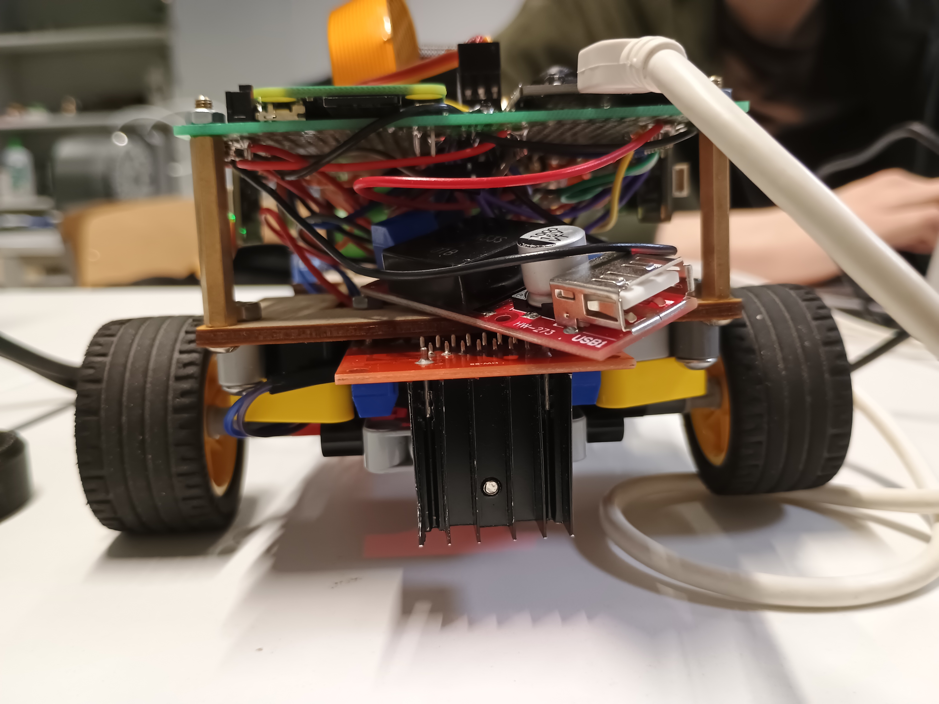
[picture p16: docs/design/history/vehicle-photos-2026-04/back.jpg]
<tr><td></td><td></td></tr>
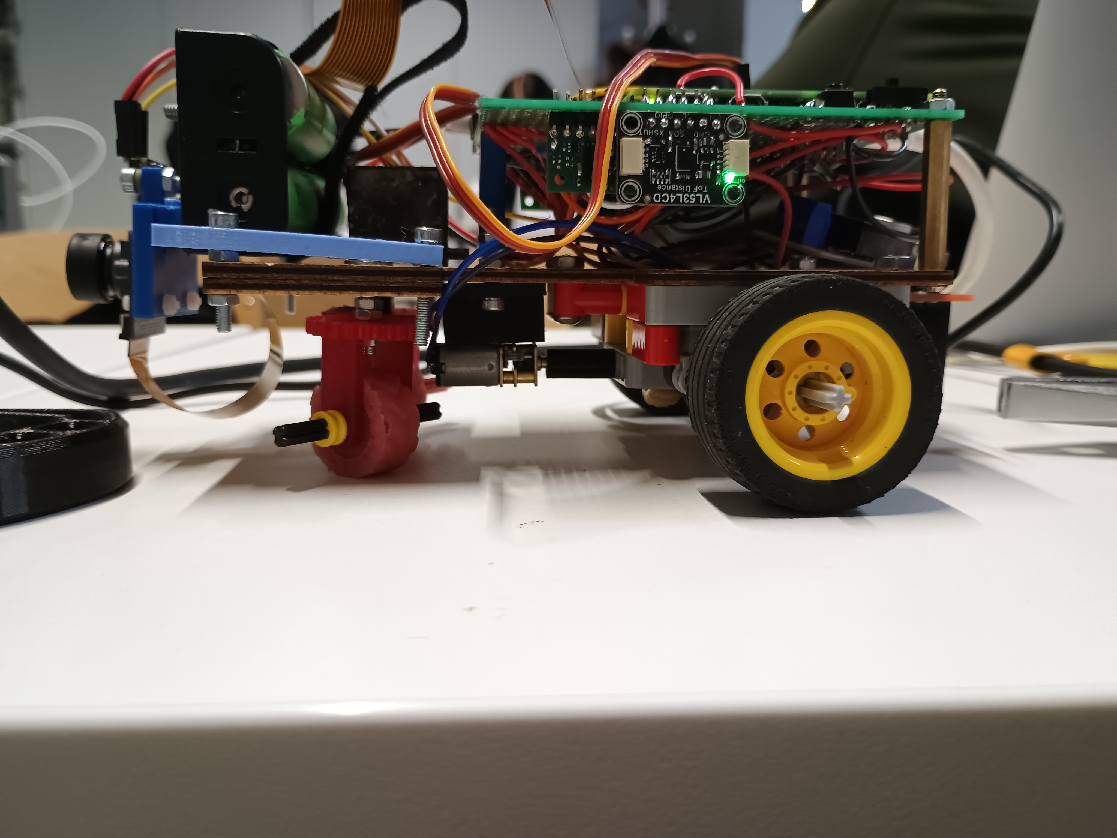
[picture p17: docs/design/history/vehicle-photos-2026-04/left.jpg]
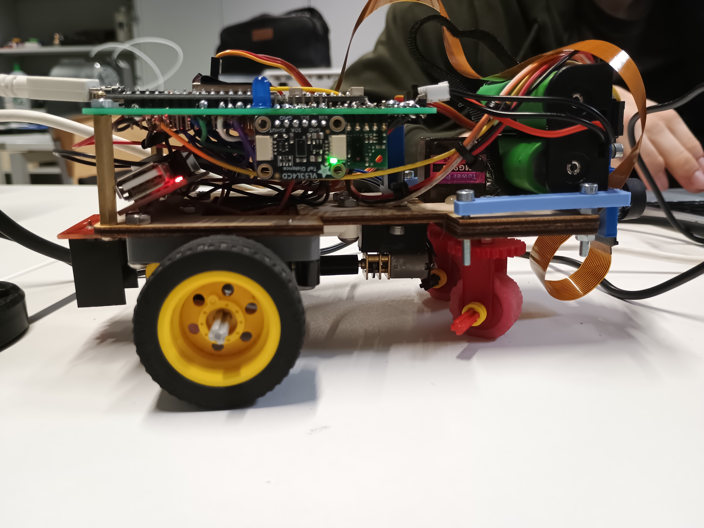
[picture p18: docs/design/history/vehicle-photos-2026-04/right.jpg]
<tr><td></td><td></td></tr>
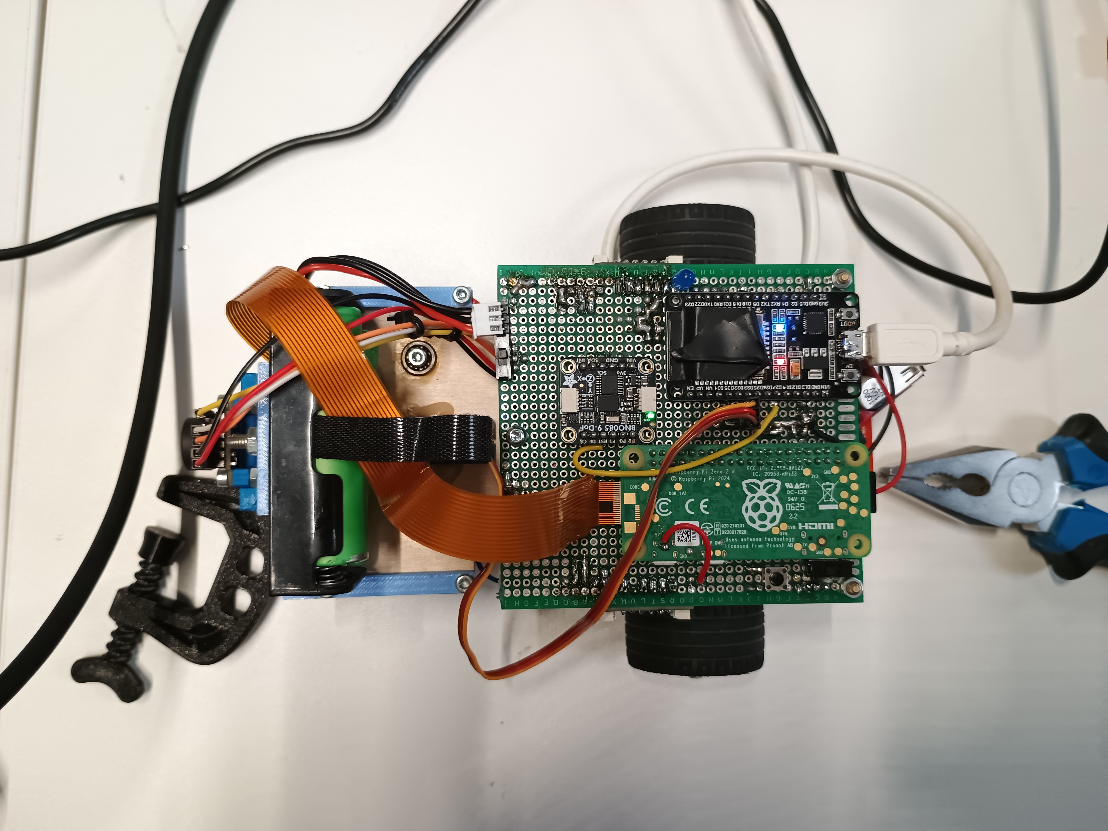
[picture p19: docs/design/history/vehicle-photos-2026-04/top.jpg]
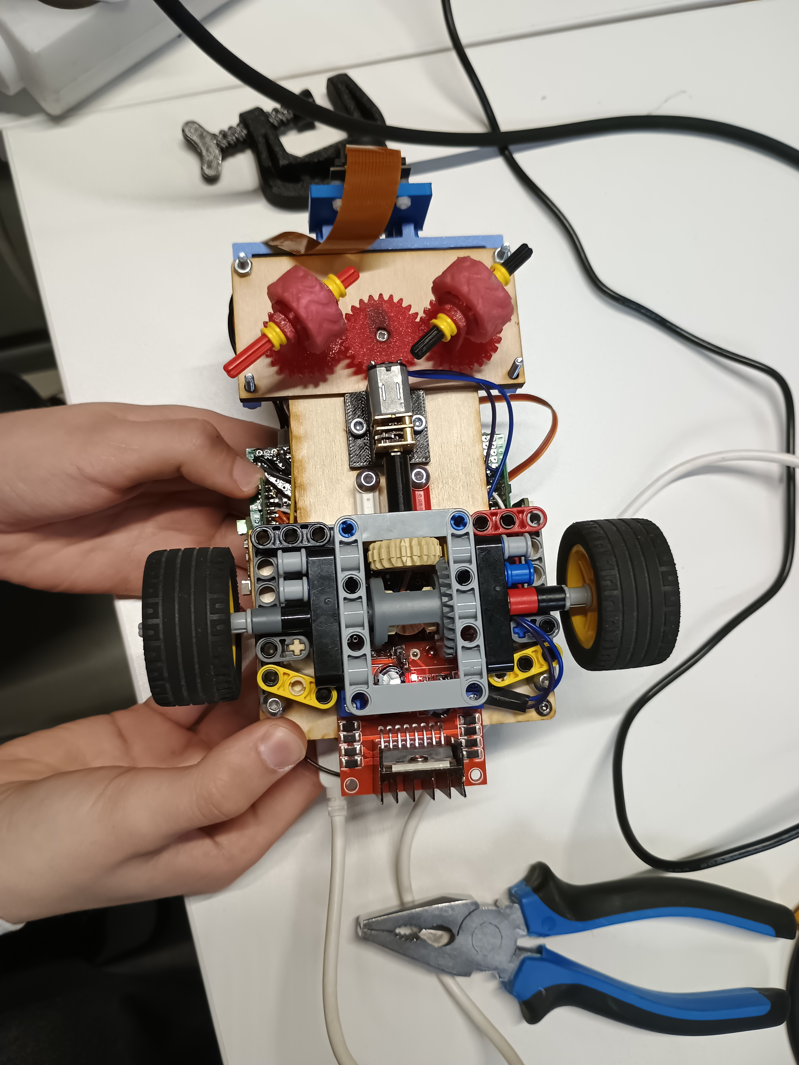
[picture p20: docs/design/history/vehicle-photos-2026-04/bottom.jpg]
<tr><td></td><td></td></tr>
</table>

This is the earlier packaging baseline. The later car is smaller and uses less hardware.

## Stage 2: differential and drivetrain

<table>
<tr><td></td><td></td></tr>
</table>

## Stage 3: steering

<table>
<tr><td></td><td></td></tr>
</table>

## Stage 4: electronics integration

<table>
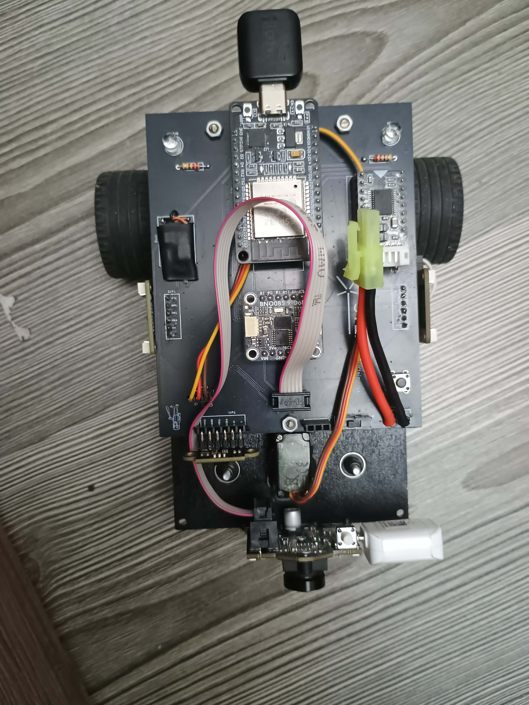
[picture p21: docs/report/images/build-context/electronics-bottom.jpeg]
<tr><td></td><td></td></tr>
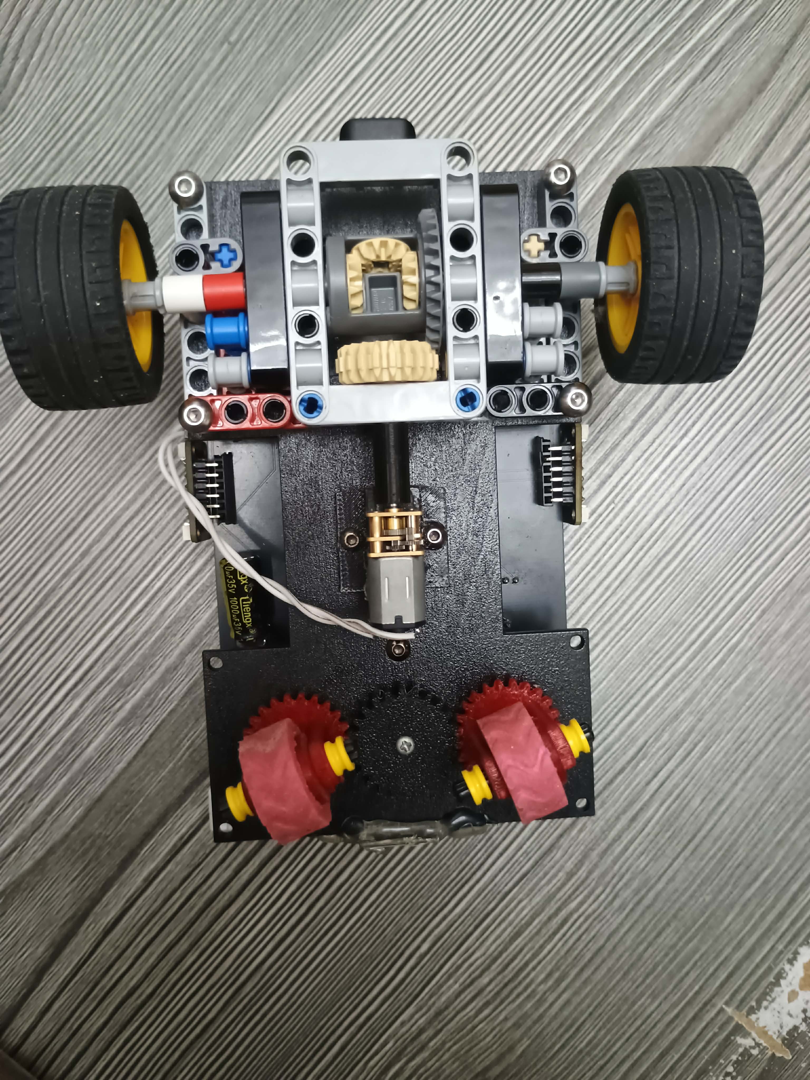
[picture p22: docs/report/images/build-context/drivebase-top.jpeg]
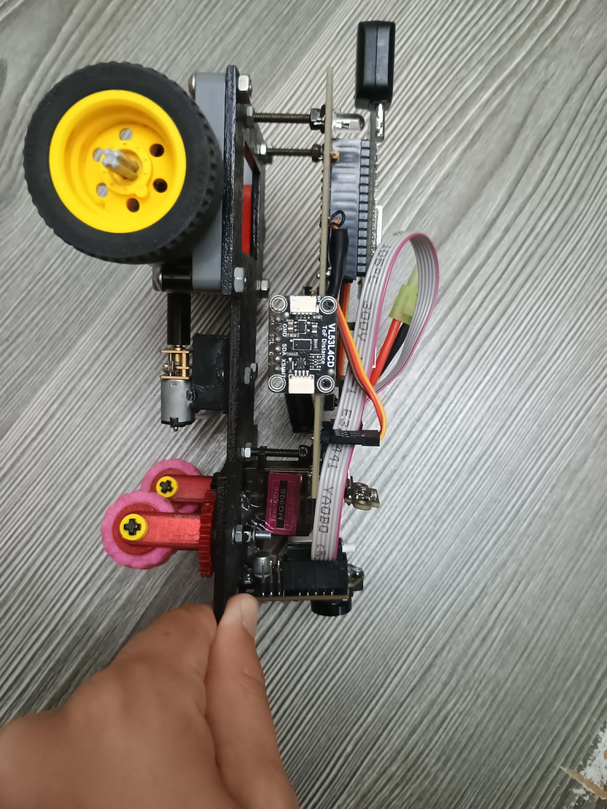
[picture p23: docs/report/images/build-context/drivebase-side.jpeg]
<tr><td></td><td></td></tr>
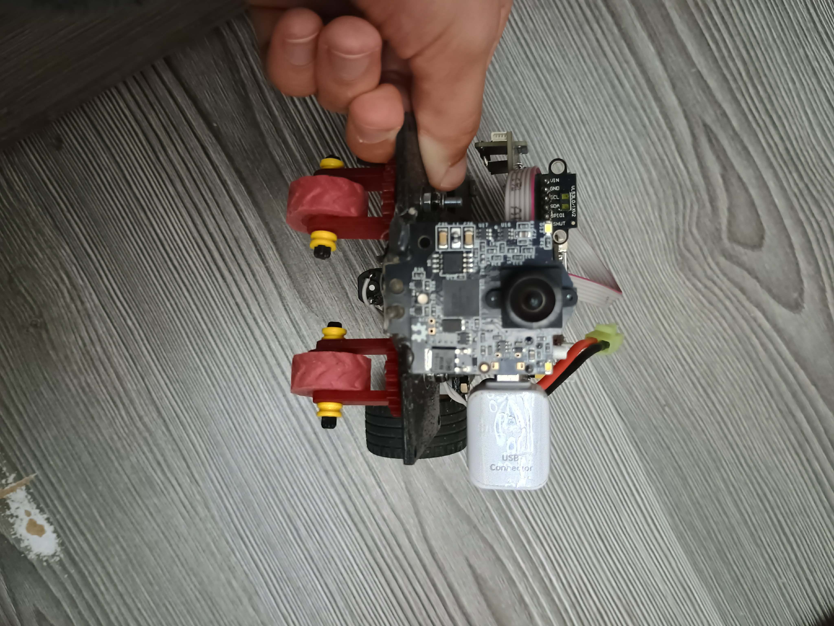
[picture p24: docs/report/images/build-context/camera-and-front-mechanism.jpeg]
<tr><td colspan="2" align="center"></td></tr>
</table>

## Stage 5: final competition robot

The five photos near the top show the final robot with the black PCB and white rear wheels.

---

# 7. Bill of materials and sourcing

The supplier links are examples. Match each part to the model, footprint and electrical or mechanical interface listed here.

| Qty | Component | Final specification | Example source | Important detail |
|---:|---|---|---|---|
| 1 | ESP32 board | ESP32-WROOM-32 DevKit V1, **30 pin** | [3DSVET EU](https://www.3dsvet.eu/izdelek/esp32-wroom32-30pinov-microusb/) | 38-pin boards do not fit the same PCB footprint |
| 1 | IMU | Adafruit BNO085, product 4754 | [Adafruit](https://www.adafruit.com/product/4754) | fixed chassis orientation |
| 3 | ToF sensor | VL53L1X on 6-pin carrier | [Pololu](https://www.pololu.com/product/3415) | the sensor itself must be VL53L1X, even if the carrier looks similar |
| 1 | Camera | Pixy2 / Pixy2.1 CMUcam5 | [RobotShop EU](https://eu.robotshop.com/products/charmed-labs-pixy-21-robot-vision-image-sensor-rbc) | direct ESP32 SPI connection through the custom PCB |
| 1 | Steering servo | TowerPro MG90S positional | [Anodas LT](https://www.anodas.lt/en/towerpro-mg90s-micro-analog-servo-with-metal-gear) | do not use 360° continuous rotation |
| 1 | Motor driver | Makeblock MegaPi Encoder/DC Motor Driver V1 | [BerryBase](https://www.berry-base.com/makeblock-megapi-encoder-dc-motor-driver-v1-2-kanaele-6-12-v-3-a-nennstrom-5-5-a-peak) | brushed DC output used |
| 1 | Drive motor | N20, 6 V, nominal 600 rpm, 3 mm D-shaft class | [HESTORE](https://www.hestore.eu/prod_10042830.html) | check shaft length before ordering |
| 1 | Battery | 2S LiPo, 7.4 V, 2500 mAh, 30C | RC supplier | must fit final packaging |
| 1 | 5 V regulator | Matek Micro BEC 6S, 6–30 V input, 5 V/9 V adjustable | [RCdalys](https://www.rcdalys.lt/detales/0/27234/MATEK-MICRO-BEC-6S-6-30V-5V9V-ADJUSTABLE-3PCS) | set to 5 V; 1.5 A continuous, 2.5 A max for 5 s/min |
| 1 | PCB | KU STEAM Pinkies final board | `schemes/` Gerbers | manufacture from the checked-in package |
| 1 | Rear differential | LEGO-compatible differential | LEGO/Technic source | geometry must match final drivetrain |
| 2 | Rear wheels | final white custom wheel geometry | `models/` | use final wheel CAD/material |
| 2 | Front wheel/steering assemblies | final printed/LEGO-compatible geometry | `models/` | do not scale STL files |
| 1 | Plywood base | final cut vector | `models/case.ai` | import at 1:1 scale |

### Replacement rules

- ESP32 replacements must keep the same 30-pin footprint and required GPIOs.
- ToF replacements must use VL53L1X and expose XSHUT.
- Servo must be positional, not continuous rotation.
- The 5 V regulator must meet the final Matek Micro BEC 6S electrical role: 2S-compatible input and enough continuous current for the documented 5 V load.
- N20 replacements must match voltage, speed class and shaft geometry.
- Mechanical substitutions must preserve axle, hole and wheel geometry.
- Treat any change to the pinout, sensor type, wheel size, steering geometry or camera interface as a new robot revision, and retest the robot.

---

# 8. Rebuilding the robot

Use the CAD files and steps below to rebuild the robot. Use the photos as visual references, not for measuring dimensions.

## Mechanics

1. Cut the base from `models/case.ai`.
2. Print the final STLs from `models/` without scaling.
3. Assemble the rear motor, gear stage, differential and wheels.
4. Assemble the front steering parts and MG90S.
5. Centre the linkage and verify the command range from 60° to 120°.

## Electronics

1. Manufacture the PCB from the `schemes/` Gerber/drill package.
2. Install the 30-pin ESP32 board.
3. Connect BNO085 and the three VL53L1X modules to I2C.
4. Connect XSHUT to GPIO15 / GPIO5 / GPIO18 for front / left / right.
5. Connect MG90S to GPIO33.
6. Connect the motor driver to GPIO26, GPIO25 and GPIO32.
7. Connect Pixy2 to the final board's SPI camera connector; the PCB routes `MOSI`, `MISO`, `SCK`, 5 V and GND to the camera header.
8. Check ground and supply polarity before applying motor power.

## Firmware

```bash
platformio run -d src -e open_challenge
platformio run -d src -e obstacle_challenge
```

Upload the build for the required challenge, then run the calibration checks in section 2.6.

## Final acceptance checks

- base and printed parts match the final CAD revision;
- drivetrain turns freely;
- steering is centred and does not bind;
- front/left/right ToF identities match `0x30/0x31/0x32`;
- BNO085 heading direction is correct;
- Pixy2 image direction matches steering logic;
- ESP32 does not reset during hard steering and acceleration;
- only trained Pixy2 signatures 1/2 influence obstacle steering (regression test still required);
- the corner-exit watchdog ends a stuck turn without ongoing motor power (physical validation still required);
- both PlatformIO environments compile;
- Open Challenge straight/corner control runs without manual input;
- Obstacle Challenge recognises the trained signatures, passes and recovers to normal driving;
- parallel parking is **not yet implemented**; do not record the entire 2026 Obstacle Challenge as complete.

---

# 9. Repository layout

```text
README.md                     project engineering journal
src/                          ESP32 PlatformIO firmware
models/                       final STL/CAD + case.ai base vector
schemes/                      schematic images, PCB PDF, Gerbers and drill files
videos/                       competition run recordings
v-photos/                     final robot photographs
t-photos/                     team photograph
docs/design/images/           drivetrain and steering development photos
docs/design/history/          earlier whole-robot photographs
docs/report/images/           build/electronics development photographs
docs/testing/                 retained validation CSV and raw-run template
```

This README is the **single engineering-journal and assessment narrative**: technical rationale, methods, results, limitations, reconstruction, testing procedures and version notes are readable here without opening another Markdown document. Source code, CAD, PCB files, CSVs, photos and videos stay in their original formats as linked supporting evidence. Build verification is manual; there is intentionally no GitHub Actions CI or `scripts/` verification directory in the current repository.

---

# 10. Versioning and verification record

This section records the competition-ready documentation state of the robot and the workflow used to keep hardware, firmware and validation evidence aligned. Git commit history provides the detailed change-by-change record, while this section identifies the current documented revision and the checks expected after material changes.

## Current competition revision

The documented competition configuration uses:

- ESP32-WROOM-32, 30-pin DevKit V1 form factor;
- BNO085 heading sensor;
- 3 × VL53L1X distance sensors in Long mode;
- Pixy2 / Pixy2.1 vision connected directly to ESP32 over SPI;
- N20 6 V motor, nominal 600 rpm;
- LEGO-compatible gearing and rear differential;
- MG90S positional steering servo;
- 2S LiPo, 7.4 V, 2500 mAh, 30C;
- custom PCB;
- approximate overall size of 165 × 145 × 70 mm;
- documented mass of 332.4 g.

The firmware is maintained as one source tree with two explicit PlatformIO environments. The currently documented Obstacle build has pillar avoidance and finish stopping, but **no autonomous parallel-parking routine**:

```bash
platformio run -d src -e open_challenge
platformio run -d src -e obstacle_challenge
```

- `open_challenge` uses `WRO_CHALLENGE_MODE=0`;
- `obstacle_challenge` uses `WRO_CHALLENGE_MODE=1`.

## Reproducibility package

The repository keeps the material needed to rebuild, inspect and validate the documented robot in version control:

- `README.md` — design reasoning, architecture, calibration, tuning, rebuild instructions and this versioning record;
- `src/` — ESP32 PlatformIO firmware;
- `models/` — final STL/CAD files and `case.ai`;
- `schemes/` — PCB documentation, Gerbers, drill files and schematic images;
- `docs/testing/validation-summary.csv` — retained validation summary;
- `docs/testing/raw/run-template.csv` — repeatable run-record format;
- `README.md` section 5 — the full test protocol, metric definitions, evidence requirements and historical result context;
- `v-photos/` — final robot photographs;
- `t-photos/` — team photograph;
- `videos/` — competition run recordings.

## Verification workflow for a material revision

When a material robot revision is made:

1. record the Git commit SHA used for the revision;
2. build both PlatformIO environments;
3. repeat the calibration checks in section 2.6;
4. repeat the final acceptance checks in section 8;
5. record new physical runs using `docs/testing/raw/run-template.csv`;
6. update `docs/testing/validation-summary.csv` from retained measurements;
7. document what changed, why it changed and which subsystem was affected.

A change to pinout, sensor type, wheel size, steering geometry, camera interface or challenge-control behaviour is treated as a new robot revision and is rechecked before its results are used as final competition evidence.

## Revision trace

The Git history provides the detailed evolution of the project. Meaningful commits cover the major documented revisions, including chassis and drivetrain development, steering redesign, sensor architecture changes, custom PCB integration, Pixy2 SPI correction, testing workflow updates and final power/sensor/calibration documentation. Together with the robot-evolution section and retained test results, this provides traceability from earlier prototypes to the current competition configuration.

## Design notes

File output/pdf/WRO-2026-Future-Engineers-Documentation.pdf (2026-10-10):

# KU STEAM Pinkies: WRO 2026 Future Engineers

We are KU STEAM Pinkies from Klaipėda University STEAM Centre. For WRO 2026 Future Engineers, we built a compact rear-wheel-drive, front-wheel-steer robot with an ESP32, a BNO085 heading sensor, three VL53L1X distance sensors and Pixy2 vision.

We gave each subsystem one job. If hardware added wiring, latency or failure points without giving us useful information, we left it out.

## Team

Domas Lukas (left)
Jonas Danisevičius(right)
Marius Plečkaitis(center)

## Competition videos

Open Challenge: https://youtu.be/wYDWJLPF3cQ Obstacle Challenge: https://youtu.be/kq5EeDzJqs0

## Contents

Final robot
Mechanical design
Electronics, power and sensors
Software architecture
Engineering decisions and system development

Testing and tuning
Robot evolution
Bill of materials and sourcing Rebuilding the robot
Repository layout
Versioning and verification record

# Final robot

The final competition robot has a black custom PCB and white rear wheels.

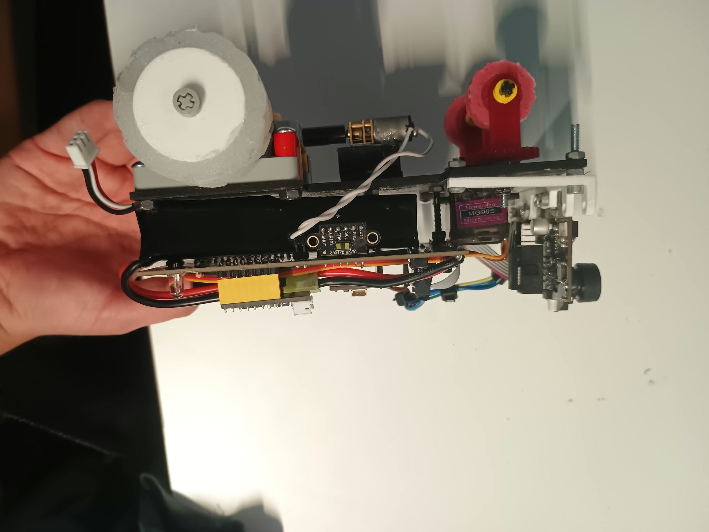
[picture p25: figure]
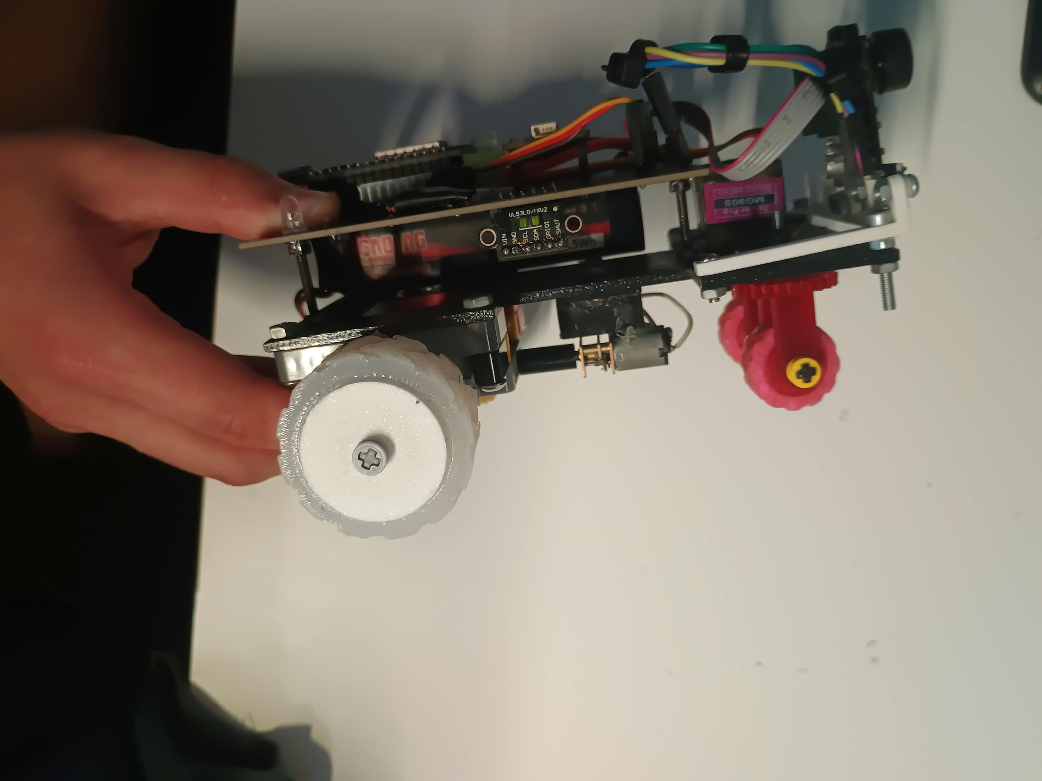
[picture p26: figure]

Final robot, right side | Final robot, left side

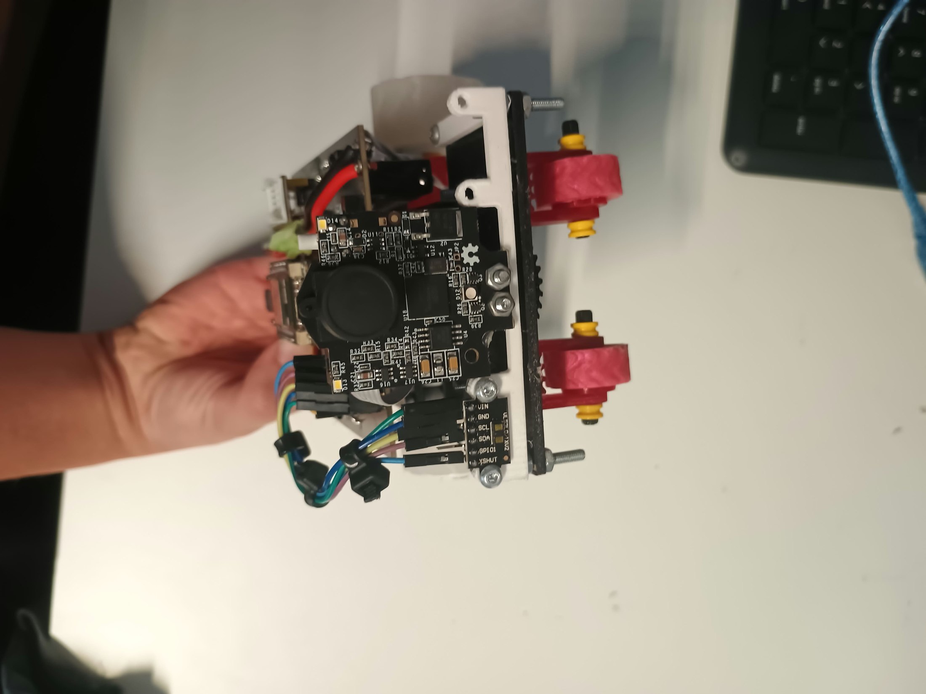
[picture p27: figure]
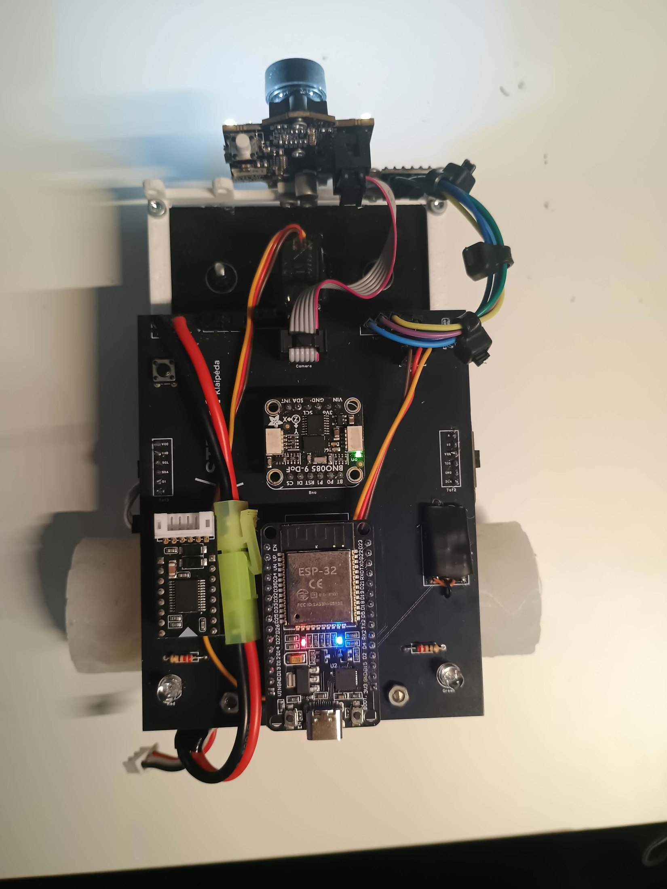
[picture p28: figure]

Final robot, front | Final robot, top

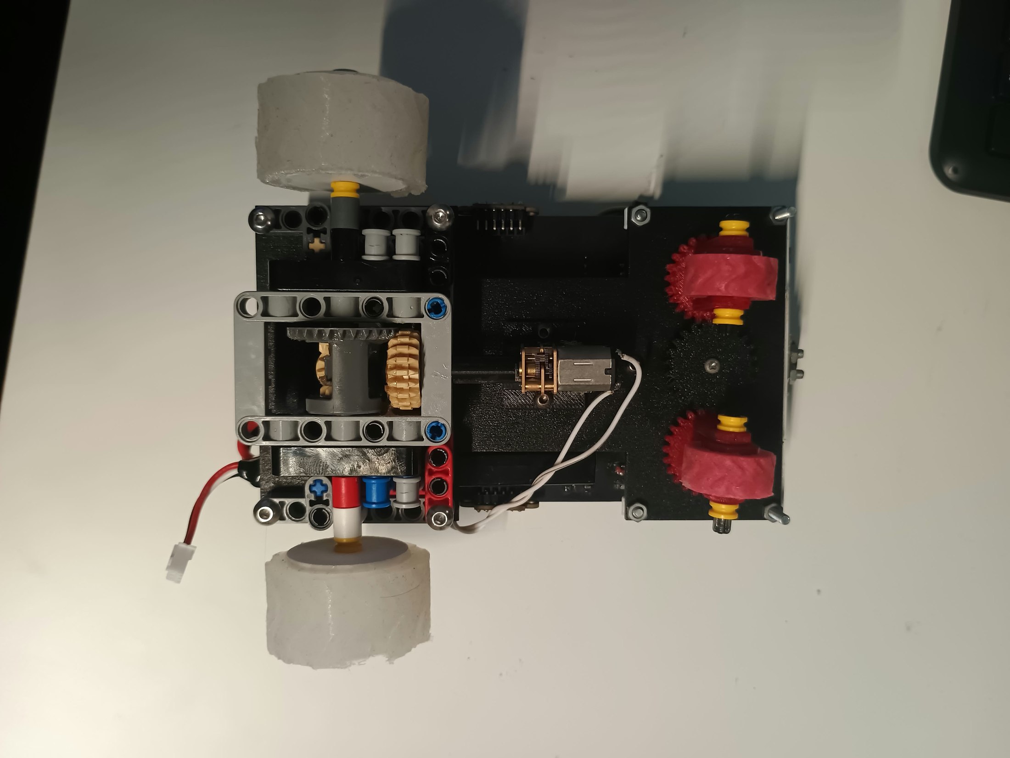
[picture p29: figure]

Final robot, bottom

Subsystem | Final version
Controller | ESP32-WROOM-32, 30-pin DevKit V1 form factor
Heading | BNO085
Range sensing | 3 × VL53L1X, Long mode
Vision | Pixy2 / Pixy2.1
Drive | rear-wheel drive
Motor | N20, 6 V, nominal 600 rpm
Transmission | LEGO-compatible gearing + LEGO differential
Steering | front-wheel steering, positional MG90S
Battery | 2S LiPo, 7.4 V, 2500 mAh, 30C
5 V regulator | Matek Micro BEC 6S, 6–30 V input, 5 V/9 V adjustable, used at 5 V
Electronics | custom PCB
Mass | 332.4 g
Approx. overall size | 165 × 145 × 70 mm

# 1. Mechanical design

## 1.1 Layout

We chose rear-wheel drive and front-wheel steering. That leaves the rear axle to provide traction and the front mechanism to steer. The layout also simplified the control model and left room in the centre of the chassis for the battery, PCB and sensors.

We kept the car compact to leave more room around corners and obstacles and reduce the steering correction needed after a turn.

## 1.2 Drivetrain

N20 geared motor

↓

shaft adapter

↓

LEGO-compatible gear stage

↓

LEGO differential

↓

rear wheels

The nominal motor speed is 600 rpm. With the final effective reduction of about 1.50:1:

wheel_rpm = 600 / 1.50 = 400 rpm

wheel circumference = π × 0.054 = 0.1696 m

ideal geometric speed = 400 × 0.1696 / 60 ≈ 1.13 m/s

The 0.08 N·m motor-torque value comes from the official motor specification. The 80% drivetrain efficiency is an engineering assumption used for the design calculation rather than a measured efficiency value:

wheel torque ≈ 0.08 × 1.50 × 0.80 = 0.096 N·m

tractive force ≈ 0.096 / 0.027 ≈ 3.6 N

The drivetrain model was used to select the final gearing before integration. We balanced wheel speed against the torque reserve needed for acceleration, steering drag and repeated corner exits. More reduction increases wheel torque but lowers lap speed, while less reduction increases speed at the cost of control margin. The final 1.50:1 ratio gives a compact drivetrain with enough calculated tractive force for the 332.4 g vehicle while keeping the target wheel speed within the controller's useful operating range.

The N20 motor was selected because its compact geared form factor fits the rear-drive layout, aligns cleanly with the LEGO-compatible transmission and provides the required combination of speed and torque without adding another transmission stage.

## 1.3 Differential iteration

Earlier metal differential | Final LEGO differential

We kept the LEGO differential because it fits the rest of the LEGO-compatible axle and gearing directly, uses fewer custom couplings and is easier to replace during competition. It also allows the two rear wheels to rotate at different speeds in a corner.

## 1.4 Steering iteration

Earlier steering | Final steering

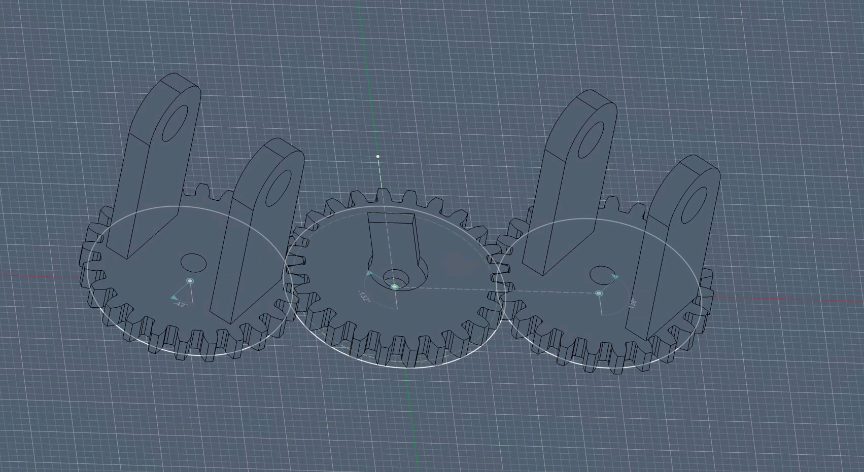
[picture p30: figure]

The final steering uses a positional MG90S servo. We chose this servo because the steering mechanism needs repeatable absolute positioning in a compact package, and its form factor integrates directly with the front linkage. We centre the linkage mechanically before fixing the servo horn. Firmware limits the servo command from 60° to 120°, with 88° as straight ahead. The final linkage is approximately 1:1 in angular movement around the centre position, so the controller endpoints correspond approximately to −28° and +32° of wheel steering relative to the 88° straight position. These endpoint angles are derived from the linkage relationship and firmware commands; they are not separate protractor measurements. The limits keep the linkage inside the mechanically useful steering range and improve repeatability between runs.

The steering redesign reduced the observed space needed for a 90° turn from about 46 cm to 39 cm, supporting the final compact linkage and steering-range choice.

## 1.5 CAD and base fabrication

The final custom parts are in models/ :

Current file in models/ | Earlier name in Git history | Identification / verification note
Front.stl | unchanged | front-assembly geometry
Front_wheel_gear.stl | Body1.stl | formerly documented as body/structural geometry
Front_wheel.stl | motor-shaft-spacer.stl | formerly documented as motor-shaft spacer
Rear_wheel_mold.stl | lego-mold-su-x.stl | formerly documented as LEGO-interface mould/part
Front_wheel_gear(1).stl | steering-column-housing-short.stl | formerly documented as steering-column housing
middle_gear_steering.stl | steering-gear-cover-disc.stl | formerly documented as steering gear-cover disc
Front_wheel_mold(1).stl | steering-gear-hub.stl | formerly documented as steering-gear hub
Front_wheel_mold.stl | steering-gear-plate.stl | formerly documented as steering-gear plate
Motor_adapter.stl | steering-pin-adapter.stl | formerly documented as steering-pin adapter
case.ai | unchanged | 2D plywood/base cutting vector

File identity note: These are the actual names present in the checked-in final CAD package. The previous names and descriptions come from the README and Git rename history, not from newly verified CAD assembly constraints. Some newer filenames do not match the earlier descriptions; identify installation positions by inspecting the STL geometry alongside the final robot photos. The former ratas-su-x.stl file was deleted and is not required for this revision. Do not follow older file lists or silently substitute a missing model.

models/case.ai is the base fabrication file. Its main rectangular path is approximately 90 × 150 mm when imported at the original scale. That number is only a scale check; holes, slots and curves must be taken from the vector itself.

Mechanical build order:

1. cut models/case.ai at 1:1 scale;
2. print the STL parts without rescaling;
3. mount the N20 motor and motor-shaft interface;
4. assemble the LEGO-compatible gear stage and rear differential;
5. install the rear wheels and confirm both sides rotate freely;
6. assemble the front steering parts and MG90S;
7. centre the steering mechanically;
8. check the full range from 60° to 120° for binding;
9. mount the electronics stack and compare the result with the final photos above.

Standard LEGO Technic shafts and gears, along with ordinary fasteners, are not performance-tuned. Replace them only with parts that keep the shaft, hole and mounting geometry shown in the CAD and final assembly.

# 2. Electronics, power and sensors

## 2.1 Power architecture

The final battery is 2S LiPo, 7.4 V, 2500 mAh, 30C.

2S LiPo (7.4 V)

+--> custom PCB --> motor driver --> N20 motor

+--> Matek Micro BEC 6S (set to 5 V) --> 5VLINE --> ESP32 / BNO085 / VL53L1X / Pixy2 / MG90S

Battery energy:

E = 7.4 V × 2.5 Ah = 18.5 Wh

### Current budget used during design

Load | Normal | Short peak | Main concern
ESP32 | ~160 mA | ~240 mA | logic stability
BNO085 | ~15 mA | ~20 mA | heading stability
3 × VL53L1X | ~75 mA total | ~120 mA total | ranging / I2C stability
Pixy2 | ~140 mA | ~200 mA | camera processing
MG90S | ~200–300 mA | ~750 mA | steering peak/stall
N20 motor | ~350 mA | ~1.3 A | acceleration/stall
whole robot | ~0.9–1.2 A | ~1.8–2.2 A coincident design peak; ~2.63 A if every listed individual peak is summed simultaneously | regulator and connector voltage drop

The PCB netlist shows the 7.4 V battery rail feeding the Matek Micro BEC 6S, configured for 5 V, whose output is the board's 5VLINE . The regulator is specified for a 6–30 V input, 5 V or 9 V adjustable output (5 V default), 1.5 A continuous load, and 2.5 A maximum for 5 s/minute. It also specifies over-current protection, thermal shutdown and short-circuit tolerance. Product reference: https://www.rcdalys.lt/detales/0/27234/MATEK-MICRO-BEC-6S-6-30V-5V9V-ADJUSTABLE-3PCS

The 5 V branch supplies the ESP32, BNO085, three VL53L1X modules, Pixy2 and MG90S. Using the component peak values in the table above, the listed 5 V loads sum to approximately 1.33 A, below the BEC's 1.5 A continuous rating. The N20 motor is supplied through the separate battery/motor-driver path, so its current is not part of the BEC load. The individual peak figures are component-level design values; the whole-robot 1.8–2.2 A figure is the expected coincident operating peak because all listed component maxima do not normally occur at exactly the same instant.

## 2.2 Custom PCB

PCB layout | PCB routing

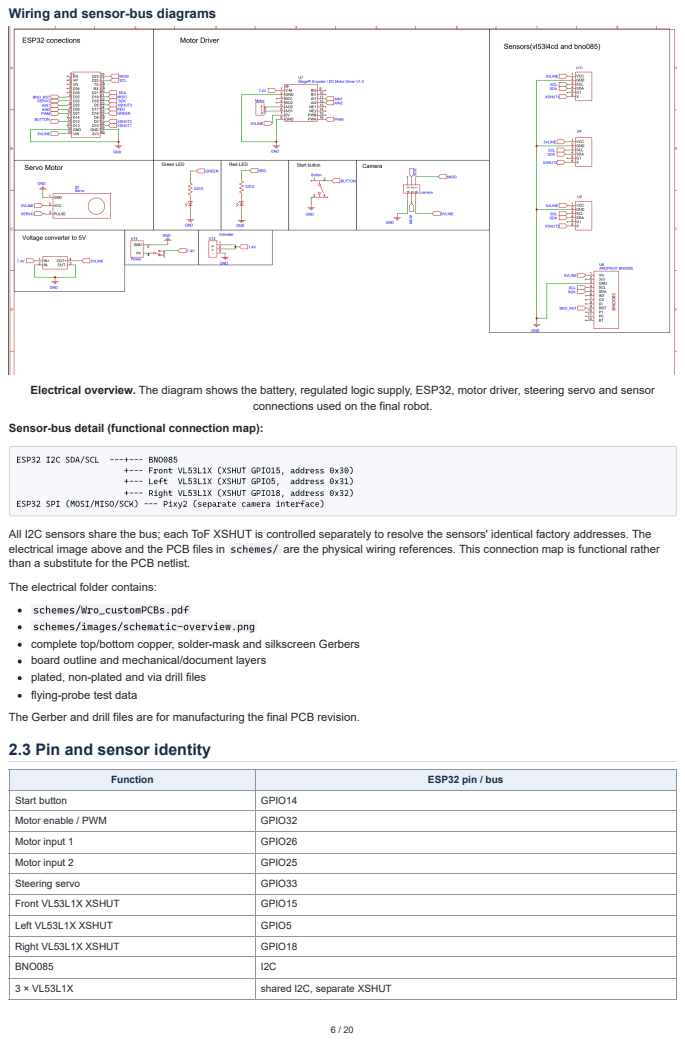
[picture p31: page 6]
ESP32 I2C SDA/SCL; - +- BNO085; +- Left; VL53L1X (XSHUT GPIO5,; address 0x31); schemes/Wro_customPCBs.pdf

Wiring and sensor-bus diagrams

Electrical overview. The diagram shows the battery, regulated logic supply, ESP32, motor driver, steering servo and sensor

connections used on the final robot.

Sensor-bus detail (functional connection map):

+- Front VL53L1X (XSHUT GPIO15, address 0x30)

+- Right VL53L1X (XSHUT GPIO18, address 0x32)

ESP32 SPI (MOSI/MISO/SCK) - Pixy2 (separate camera interface)

All I2C sensors share the bus; each ToF XSHUT is controlled separately to resolve the sensors' identical factory addresses. The
electrical image above and the PCB files in schemes/ are the physical wiring references. This connection map is functional rather
than a substitute for the PCB netlist.
The electrical folder contains:

schemes/images/schematic-overview.png
complete top/bottom copper, solder-mask and silkscreen Gerbers
board outline and mechanical/document layers
plated, non-plated and via drill files
flying-probe test data
The Gerber and drill files are for manufacturing the final PCB revision.
2.3 Pin and sensor identity

Function | ESP32 pin / bus

Start button | GPIO14
Motor enable / PWM | GPIO32
Motor input 1 | GPIO26

Motor input 2 | GPIO25
Steering servo | GPIO33
Front VL53L1X XSHUT | GPIO15

Left VL53L1X XSHUT | GPIO5
Right VL53L1X XSHUT | GPIO18
BNO085 | I2C

3 × VL53L1X | shared I2C, separate XSHUT

Function | ESP32 pin / bus
Pixy2 | SPI on custom PCB (MOSI / MISO / SCK)

All three ToF modules share the same factory I2C address. Firmware enables them one at a time and assigns each a different runtime address:

Sensor | XSHUT | Runtime address
Front | GPIO15 | 0x30
Left | GPIO5 | 0x31
Right | GPIO18 | 0x32

## 2.4 Sensor placement and track geometry

The front VL53L1X faces forward on the robot centreline, beside the Pixy2 camera. It measures forward clearance and helps detect a corner; Pixy2 independently reports the position of coloured obstacles. The left and right VL53L1X modules are installed directly in the dedicated ToF positions provided by the custom PCB, at its lateral sides, and measure the corresponding side clearances for wall correction. Their placement is therefore fixed by the checked-in PCB layout rather than by an arbitrary hand-measured mounting offset. The chassis-mounted BNO085 provides heading, so range and orientation feedback come from separate sensors.

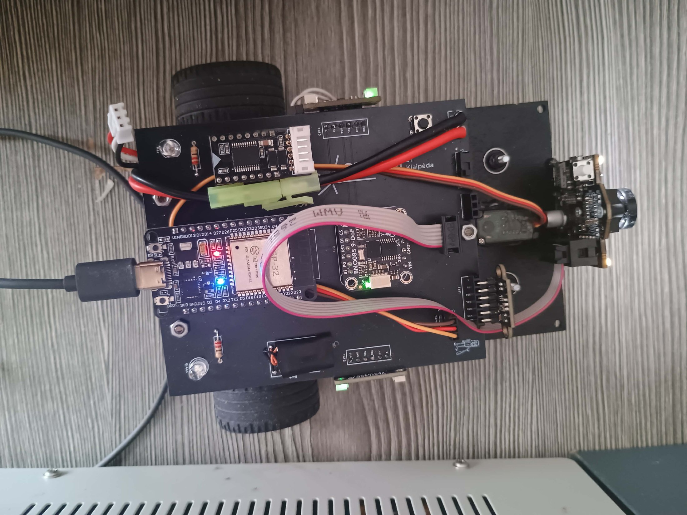
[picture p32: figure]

Installed sensor positions. Left and right VL53L1X modules sit at the PCB side edges; the front VL53L1X is beside Pixy2.

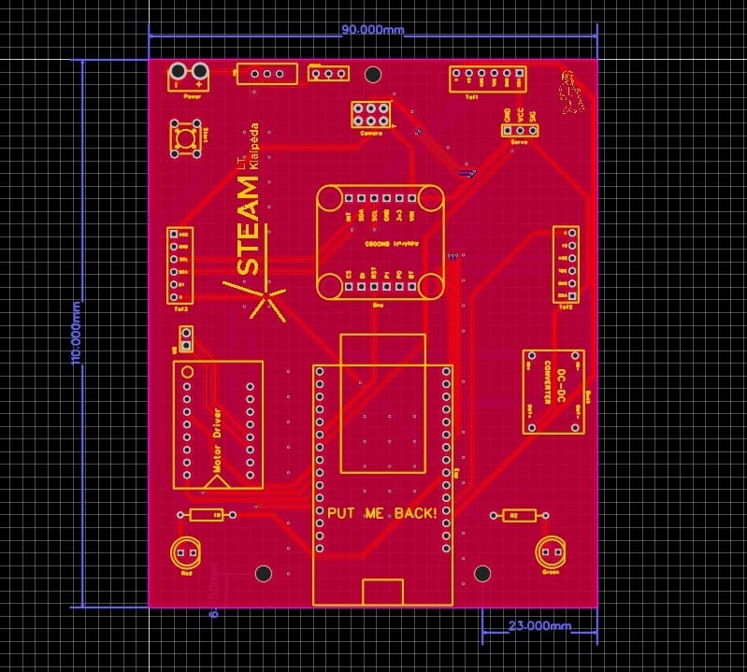
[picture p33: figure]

PCB footprint. The drawing marks the board as 90 × 100 mm.

The robot's documented overall dimensions are approximately 165 × 145 × 70 mm.

### Projection onto the WRO corridor

The WRO 2026 Future Engineers rules (https://wro.hr/wp-content/uploads/2026/01/WRO-2026-Future-Engineers-Self-Driving-Cars-General-Rules.pdf) specify nominal corridor widths of 600 mm or 1000 mm for Open Challenge, and 1000 mm for Obstacle Challenge. The Open Challenge width may vary by ±100 mm at the International Final; Obstacle Challenge specifies ±10 mm.

For the corridor model, the 90 mm PCB dimension runs across the robot, with the left and right ToF modules positioned at the two lateral PCB edges. The centred-reference calculation below shows how that sensor spacing relates to the nominal WRO corridor widths and to the documented 145 mm vehicle width.

WRO section | Nominal corridor width | Side sensor centre to nearest wall, centred | Robot body side to wall, centred
Open Challenge, narrow corridor | 600 mm | ≈255 mm | ≈227.5 mm
Open Challenge, wide corridor | 1000 mm | ≈455 mm | ≈427.5 mm
Obstacle Challenge | 1000 mm | ≈455 mm | ≈427.5 mm

Calculation: sensor-to-wall = (corridor width − 90 mm) / 2 ; body clearance uses the documented 145 mm vehicle width: (corridor width − 145 mm) / 2 . Firmware uses ROBOT_WIDTH = 150 mm as its rounded control model.

Plan view — schematic, not to scale

600 mm corridor:
LEFT WALL │← ≈255 mm →│ ● Left ToF ── ≈90 mm ── Right ToF ● │← ≈255 mm →│ RIGHT WALL

1000 mm corridor:
LEFT WALL │← ≈455 mm →│ ● Left ToF ── ≈90 mm ── Right ToF ● │← ≈455 mm →│ RIGHT WALL

Robot layout (body width ≈145 mm):

FRONT / direction of travel ↑

+----------------------------------------------+

| Front VL53L1X beside Pixy2 camera | |
| Left ToF | [PCB 90 × 100 mm] | Right ToF | |

+----------------------------------------------+

The firmware's | TARGET_DISTANCE=300 mm | is a side-wall setpoint while the current section width is unknown; in the Obstacle
Challenge build, section width is not learned, so normal wall following uses that 300 mm target. At the nominal centred geometry, this is 45 mm farther from the selected wall than the 600 mm corridor reading (≈255 mm), and 155 mm closer to the selected wall than the 1000 mm corridor reading (≈455 mm). This comparison shows why the controller's 300 mm wall target provides a practical starting point across the two Open Challenge corridor widths while leaving the final correction to the live side-distance
measurements.

## 2.5 Sensor architecture changes

### MPU6050 → BNO085

The earlier MPU6050 setup showed noticeable yaw drift during repeated turns. Because heading error directly becomes steering error, we replaced it with BNO085 and used the IMU as the dedicated chassis-heading reference.

### Five range sensors → three VL53L1X + BNO085

With the BNO085 handling heading, we only needed three range measurements: front, left and right. We removed the other range modules and their wiring.

### VL53L4CD → VL53L1X Long mode

The side controller needs wall readings before the car gets close to a wall. VL53L1X Long mode provided a larger useful range, so we used it for all three distance sensors.

### Raspberry Pi camera chain → Pixy2 directly to ESP32 over SPI

The final PCB connects Pixy2 directly to the ESP32 using the SPI data and clock nets | MOSI , | MISO | and | SCK . This removed the
Raspberry Pi processing stage and its inter-processor communication link, reducing wiring and communication stages.

## 2.6 Calibration

ToF identity and direction

1. Put a flat target close to the left module only and check that the left channel changes.
2. Repeat for the right module.
3. Check the front sensor against a target placed on the centreline.
4. Test several known distances and record mean reading, spread and invalid samples.
5. Make sure no wheel or chassis part clips a sensor beam.

BNO085

1. Point the car along a known straight reference.
2. Record yaw.
3. Rotate the chassis about 90° and confirm the expected sign/direction.
4. Cross the 0°/360° boundary to check heading wrapping.

Pixy2

1. Open PixyMon and train the colour signatures on the actual obstacle cubes used for testing.
2. Train/check each cube individually rather than relying on one generic colour sample.
3. Repeat the signature check under different lighting conditions so the stored signatures remain usable when ambient illumination changes.
4. Place a trained obstacle near image centre and confirm that Pixy2 reports the expected signature.
5. Move it left and right and verify the reported X coordinate changes in the expected direction.
6. Check that the front structure does not block the useful image area.

The camera calibration is therefore based on PixyMon's trained colour signatures rather than fixed RGB/HSV values in the ESP32 firmware.

# 3. Software architecture

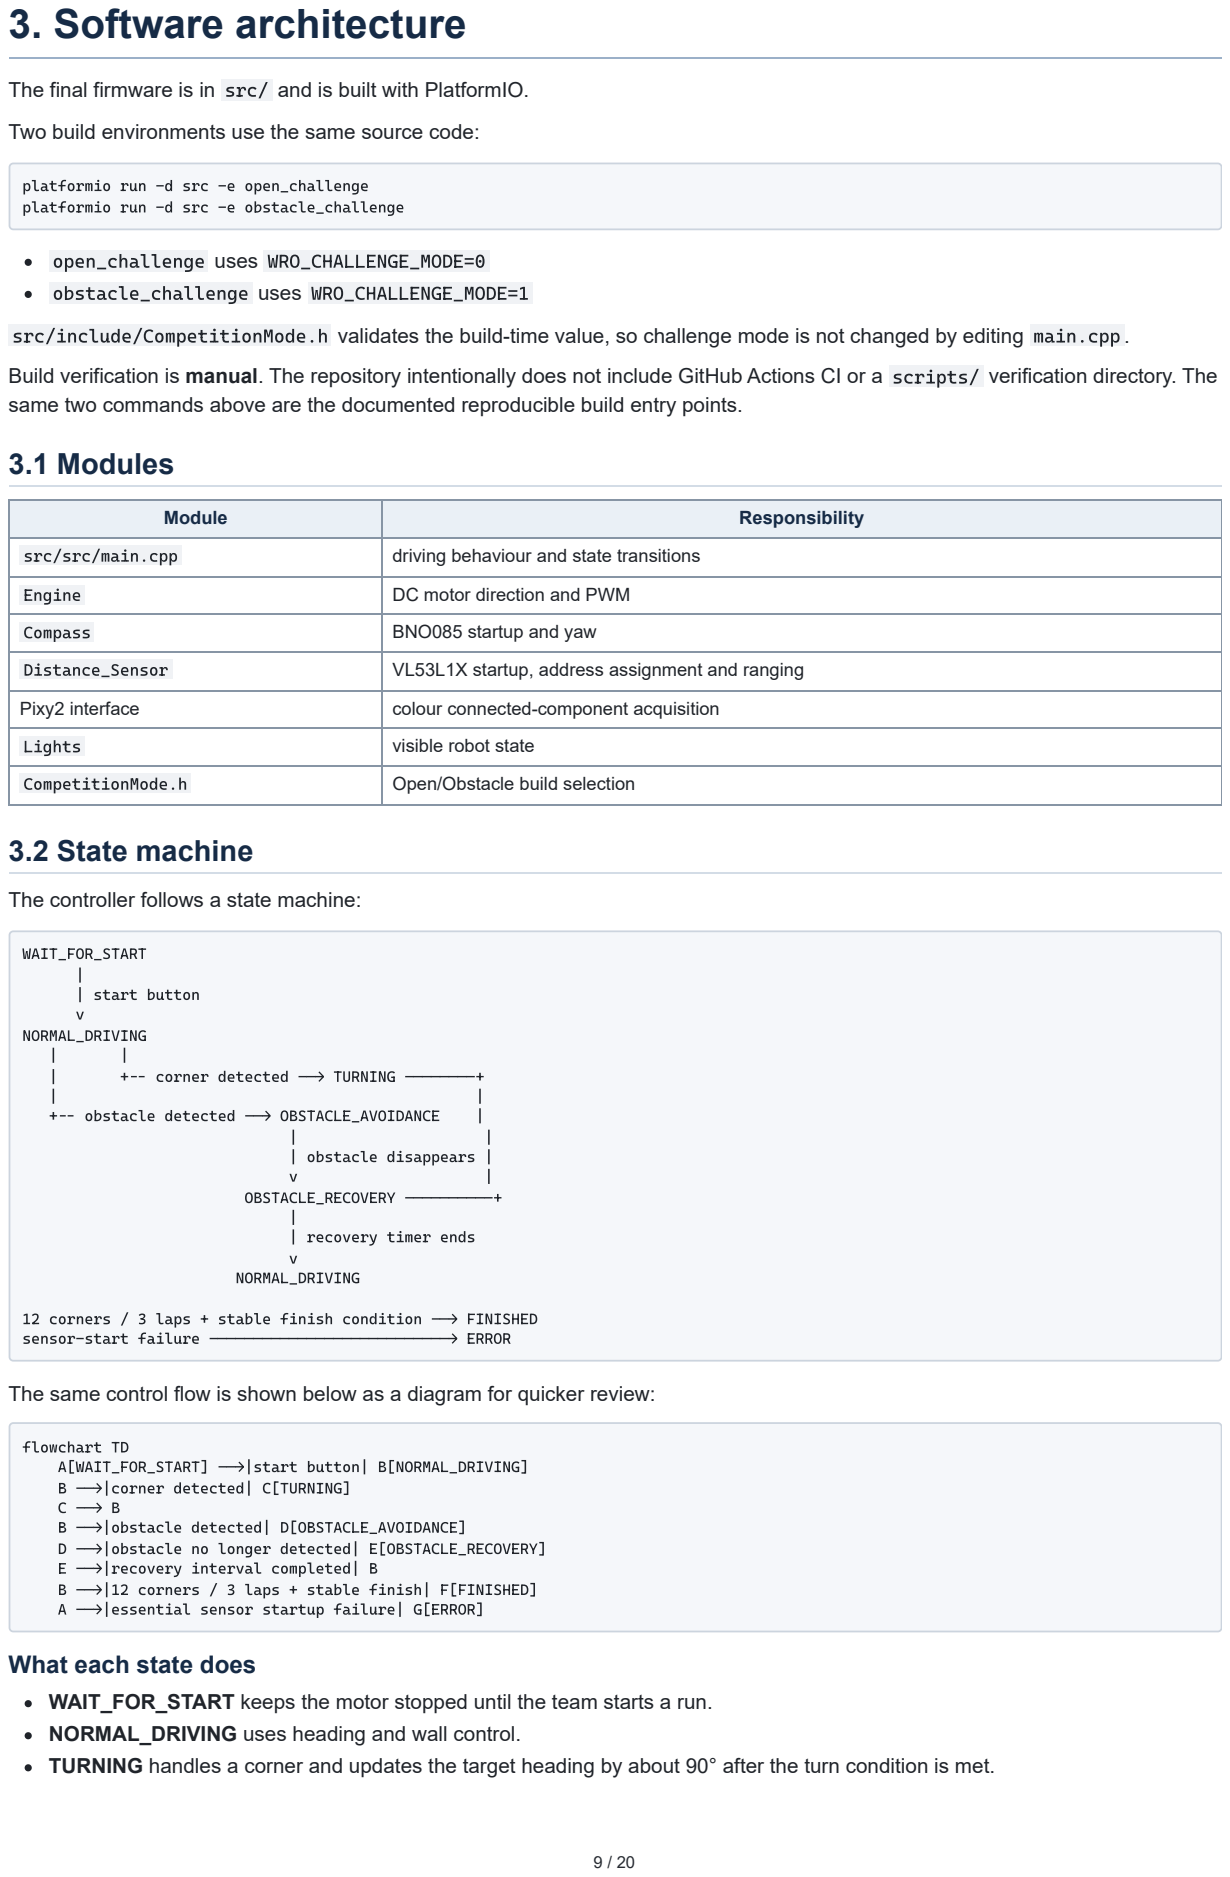
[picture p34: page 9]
open_challenge uses WRO_CHALLENGE_MODE=0; 3.2 State machine; WAIT_FOR_START |; | start button; NORMAL_DRIVING; +- corner detected --> TURNING --------+; +- obstacle detected --> OBSTACLE_AVOIDANCE; | obstacle disappears |; OBSTACLE_RECOVERY ----------+ |; | recovery timer ends; flowchart TD; A[WAIT_FOR_START] -->|start button| B[NORMAL_DRIVING]; B -->|obstacle detected| D[OBSTACLE_AVOIDANCE]

The final firmware is in src/ and is built with PlatformIO.
Two build environments use the same source code:

platformio run -d src -e open_challenge

platformio run -d src -e obstacle_challenge

obstacle_challenge uses WRO_CHALLENGE_MODE=1
src/include/CompetitionMode.h validates the build-time value, so challenge mode is not changed by editing main.cpp .
Build verification is manual. The repository intentionally does not include GitHub Actions CI or a scripts/ verification directory. The
same two commands above are the documented reproducible build entry points.
3.1 Modules

Module | Responsibility

src/src/main.cpp | driving behaviour and state transitions

Engine | DC motor direction and PWM
Compass | BNO085 startup and yaw
Distance_Sensor | VL53L1X startup, address assignment and ranging

Pixy2 interface | colour connected-component acquisition
Lights | visible robot state
CompetitionMode.h | Open/Obstacle build selection

The controller follows a state machine:

12 corners / 3 laps + stable finish condition --> FINISHED
sensor-start failure ---------------------------> ERROR

The same control flow is shown below as a diagram for quicker review:

B -->|corner detected| C[TURNING]

D -->|obstacle no longer detected| E[OBSTACLE_RECOVERY]
E -->|recovery interval completed| B

B -->|12 corners / 3 laps + stable finish| F[FINISHED]
A -->|essential sensor startup failure| G[ERROR]
What each state does
WAIT_FOR_START keeps the motor stopped until the team starts a run.
NORMAL_DRIVING uses heading and wall control.
TURNING handles a corner and updates the target heading by about 90° after the turn condition is met.

OBSTACLE_AVOIDANCE gives Pixy2 steering priority while an obstacle block is present.
OBSTACLE_RECOVERY keeps wall following from taking over while the car is still angled after passing an obstacle. FINISHED keeps the robot stopped after the coded three-lap finish condition. It does not execute parallel parking. ERROR stops the run if an essential sensor fails during startup.

## 3.3 Heading and wall control

Heading error is wrapped to the shortest direction:

heading_error = target_heading - yaw

if heading_error > 180: heading_error -= 360

if heading_error < -180: heading_error += 360

Heading error sets the base steering correction. A derivative damping term is included to reduce abrupt steering changes and improve stability as the robot converges back toward its target heading.

Wall correction uses the outside wall:

wall_error = measured_outer_wall_distance - target_wall_distance

Clockwise runs use the left outer wall, and counter-clockwise runs use the right. The controller accepts a range reading only when its status and the combined left and right distances are plausible.

The steering command is conceptually:

straight centre

+ heading correction

+ wall-distance correction

+ derivative damping

+ Pixy2 correction when avoiding an obstacle

Servo output is clamped to the mechanical range.

## 3.4 Corner strategy

When the front ToF detects a corner, the controller enters TURNING . If the driving direction is not set yet, it locks one in, steers to the turn limit and waits for the sensor to show that the car has cleared the corner. It then updates the target heading by about 90° and

returns to NORMAL_DRIVING .

The front ToF tells the controller when to turn; BNO085 provides the heading the car should recover to.

## 3.5 Obstacle strategy

In obstacle_challenge , Pixy2 CCC blocks go straight to the ESP32. The controller filters detections by height so tiny or oversized blocks do not trigger steering.

Among the remaining blocks, the controller selects the block with the largest image-Y coordinate as a camera-image proximity heuristic (not a direct physical-distance measurement). The team trained Pixy2 signature 1 for the green pillar and signature 2 for the red pillar in PixyMon. Under the WRO rules, green must be passed on the left and red on the right. The code uses the signature-dependent horizontal image target to generate a steering correction; the sign of the resulting physical turn depends on the fitted steering mechanism and camera orientation, which must be verified on the track.

The checked-in main.cpp now accepts only Pixy2 signature 1 (green) and signature 2 (red) when selecting an obstacle block. Blocks bearing any other signature are discarded rather than being treated as red. This is a code-level robustness change; the physical behaviour with reflective objects, lighting variation and unexpected signatures still needs a recorded track test.

Current obstacle tuning constants:

Parameter | Value
Minimum block height | 8
Maximum block height | 70
Signature 1 — green offset | -105
Signature 2 — red offset | 55
Pixy steering gain | 0.32
Recovery time | 450 ms

When the obstacle disappears, the controller waits 450 ms in OBSTACLE_RECOVERY , then resumes wall control.

Current competition limitation — parking: The team's present robot does not implement autonomous parallel parking. The FINISHED state in src/src/main.cpp is a three-lap stop condition, not a parking manoeuvre. Therefore, demonstrations and performance summaries here describe driving and obstacle avoidance, not a successfully completed WRO Obstacle Challenge including parking. Parking remains an unimplemented task under the 2026 rules.

## 3.6 Controller constants

Constant | Value
ROBOT_WIDTH | 150 mm controller model
TARGET_DISTANCE | 300 mm
WIDTH_THRESHOLD | 150 mm
MIN_ANGLE | 60°
MAX_ANGLE | 120°
STRAIGHT_ANGLE | 88°
Kp | 0.09
Kg | 0.95
Kd | 0.05

## 3.7 Controller tuning and boundaries

The team iterated controller coefficients and corner behaviour during development. The final constants below are taken directly from src/src/main.cpp ; no intermediate coefficient history is available for a numeric before/after comparison.

Control element | Current code | Engineering purpose / check
Heading | angle = Kg * heading , Kg = 0.95 | Bring the robot back to the BNO085 target heading; verify both driving directions
Wall position | Kp = 0.09 applied to outer-wall distance error | Correct lateral displacement only when distance/geometry gates pass
Damping | Kd = 0.05 applied to an error-difference term over elapsed time | Moderate abrupt steering changes; review overshoot on corner exit
Corner detection | Valid front ToF reading, a front-clearance threshold and combined side width ≥ 900 mm | Distinguish corner entry from normal wall following
Corner steering | Servo limited to 60° or 120° during the turn | Keep the command inside the chosen mechanical travel
Corner counting | One increment after the front-distance turn-exit condition | Track the required 12 corners over three laps
Normal stop | At least 12 counted corners, wall-distance error under 50 mm and heading error within 5° for 2 seconds | Avoid declaring a finish on a single instantaneous reading

The firmware handles heading wrap across 0°/360°, stops on essential ToF/BNO085 initialisation failures, ignores implausible readings for specified wall-control paths and uses a 450 ms obstacle-recovery state. These are code-level mechanisms, not claims that every physical failure has been eliminated.

Cases to test explicitly: uncertain colour classification; an unrelated Pixy2 signature; loss of valid ToF readings during a corner; heading events unavailable after start; unexpected stopping or restarting; and return to the finish area after the twelfth corner. The corner-exit while loop now has an independent 5000 ms watchdog. If it expires, the firmware stops the motor and enters ERROR rather than driving indefinitely. This is a conservative code fail-safe, not a measured or validated corner duration; verify that normal corners finish comfortably before the limit on the physical track. The FINISHED state remains a three-lap stop, not parallel parking.

## 3.8 Robustness and safeguards

The final control architecture includes several safeguards for stable competition operation:

Separate XSHUT lines allow the three ToF sensors to receive unique runtime I2C addresses during startup.
Essential distance and heading sensors are validated before motion begins.
Front ToF validity is checked at corner entry, and outer-wall readings are subject to distance/geometry gates during wall correction; some other paths, including the combined side-width condition, do not separately reject all invalid readings. Heading error is normalised to ±180° across the 0°/360° boundary.
Pixy2 detections are filtered by block size and an explicit allow-list (signatures 1 and 2) before obstacle steering is applied.

A 5000 ms corner-exit watchdog stops the drive and enters ERROR if the exit condition does not occur; physical timeout validation is pending.
Servo commands are clamped to the tested mechanical steering range.
A dedicated recovery state smooths the transition from obstacle avoidance back to wall following.
The documented current budget identifies the regulator's design margin; a dated under-load voltage/current log would be stronger physical verification.

# 4. Engineering decisions and system development

We designed around chassis size, corner clearance, steering geometry, drivetrain alignment, power stability, I2C addressing, camera view and loop latency. The robot also had to be repairable and quick to debug at a competition.

Earlier approach | Final approach | Why we changed it
larger packaging | compact chassis | more clearance and simpler layout
metal/custom differential interfaces | LEGO differential | easier integration and repair
MPU6050 | BNO085 | more useful heading reference after observed drift
five range sensors | three VL53L1X + BNO085 | clearer sensor roles and less wiring
VL53L4CD side sensing | VL53L1X Long mode | larger useful wall-ranging region
Raspberry Pi camera chain | Pixy2 directly to ESP32 over SPI | fewer processors and communication stages
prototype wiring | custom PCB | repeatable and compact electrical build
earlier Li-ion arrangement | 2S LiPo | compact package with good transient-current reserve
earlier steering linkage | revised compact linkage | better centring and less binding
implicit behaviour flags | explicit state machine | easier to understand, test and recover between behaviours

## Risk table

Failure | Effect | Mitigation
ToF address collision | no reliable distance data | independent XSHUT + 0x30/0x31/0x32 addresses
bad front range | wrong corner trigger | status check and startup validation
bad side range | wrong wall correction | range/status/geometry filtering
IMU failure | no heading reference | startup check
heading wrap | very large false error | ±180° normalisation
steering over-travel | binding / heating | mechanical centring + 60°–120° clamp
false vision block | wrong passing path | signature 1/2 allow-list, height and image-position filtering; needs physical validation
stalled corner-exit reading | indefinite turn / wall collision | 5000 ms watchdog, stop motor and enter ERROR; track validation pending
obstacle hand-back too early | oscillation after pass | dedicated recovery state
power sag | reset or sensor dropout | current margin + powered load test
loose wiring | intermittent fault | custom PCB and fixed connectors
firmware/document mismatch | hard-to-reproduce robot | Git history, two fixed PlatformIO environments, manual verification workflow and the README versioning record

# 5. Testing and tuning

## 5.1 Testing approach

The final robot was tuned through repeated mechanical, sensor, control and full-route testing. Consolidated results are stored in

docs/testing/validation-summary.csv , while docs/testing/raw/run-template.csv provides a consistent format for future
run-level validation.

We tuned the robot in this order:

1. free mechanical movement and steering centre;
2. BNO085 direction and heading response;
3. heading gain;
4. derivative damping;
5. wall-distance gain;
6. clockwise and counter-clockwise corners;
7. Pixy2 obstacle pass;
8. obstacle recovery;
9. repeated full-route attempts.

Saved results are in docs/testing/validation-summary.csv .

## 5.2 Manual verification and evidence workflow

This repository uses a manual verification workflow rather than GitHub Actions CI:

1. record the Git commit SHA for the revision being tested;
2. run platformio run -d src -e open_challenge ;
3. run platformio run -d src -e obstacle_challenge ;
4. perform the sensor calibration checks in section 2.6;
5. perform the final acceptance checks in section 8;
6. for each new physical run, copy docs/testing/raw/run-template.csv and record challenge mode, firmware SHA, battery state, changed variable, result and measured outcome;
7. update docs/testing/validation-summary.csv with the retained validation results.

The repository versioning and verification record is included in section 10 of this README. The complete repeatable test procedure, measurement definitions and evidence rules are in sections 5.3–5.6 of this README.

### Current qualitative performance estimate

The team reports approximately 8/10 successful Open Challenge driving attempts (~80%) and approximately 6/10 successful Obstacle Challenge driving/avoidance attempts (~60%) with the current robot. These are informal approximate field estimates, not ten individually recorded trials with a controlled layout. Their detailed pass/fail definitions, distributions across layouts and firmware SHAs have not been retained. In particular, the obstacle estimate excludes autonomous parking, which is not implemented. Consequently, it must not be described as a 60% success rate for completing the entire 2026 Obstacle Challenge.

The engineering development included tuning steering coefficients and corner behaviour. The current coefficient values are listed in section 3.6, and testable tuning questions are described in sections 3.7 and 5.4 of this README.

### Historical test summary and evidence provenance

The figures below reproduce the project's existing historical summary. These are archived prior estimates, not the current 8/10 and 6/10 estimates and not independently validated measurements. They are not an independently reconstructable run-by-run dataset: the original per-run logs, firmware SHA and exact field layouts for these earlier summaries were not retained. The evidence classes in docs/testing/validation-summary.csv distinguish team-reported comparisons, summary observations and retained five-value drift comparisons. The five-value calculations can be checked arithmetically, but the original measurement conditions cannot be independently re-created from the surviving records alone. New quantitative claims should be based on newly logged runs with firmware and layout identifiers.

Test | Earlier | Updated/fin al | Notes
Straight drift after 2 m | 9 cm | 4 cm | prototype → final comparison, 10 runs
Successful 3-lap runs (archived estimate, not current) | 6/10 | 9/10 | Original per-run logs unavailable; not to be used as present success rate
Corner overshoot | 14 cm | 6 cm | prototype → final comparison
Obstacle recovery | 1.2 s | 0.6 s | prototype → final comparison
Matched 3 m drift mean | 10.6 cm | 4.0 cm | five retained values per version
Open straight | — | 5/5 | final layout
Obstacle slalom | — | 4/5 | final layout
Full practice route | — | 4/5 | final layout
90° turning space | ~46 cm | ~39 cm | prototype → final comparison

For the matched 3 m drift comparison, the retained values are:

earlier: 11, 10, 12, 9, 11 cm | -> mean 10.6 cm
updated: | 4, | 5, | 3, 4, | 4 cm | -> mean | 4.0 cm

That is a 6.6 cm reduction in the retained means, about 62%.

For future physical runs, | docs/testing/raw/run-template.csv | keeps challenge mode, firmware SHA, battery state, changed
variable and measured outcome in one consistent format. The two linked YouTube videos at the top provide a visual demonstration of the final robot according to the team; they do not by themselves establish a statistically sampled success rate, nor do they establish successful parallel parking.

## 5.3 Repeatable test setup and traceability

The following procedure is for documenting future physical testing. It does not assert that tests were performed after the historical summary above. Estimated results must not be converted into invented per-run measurements.

Before changing firmware or tuning, save the full Git commit SHA and select the correct PlatformIO environment:

platformio run -d src -e open_challenge

platformio run -d src -e obstacle_challenge
Use a copy of | docs/testing/raw/run-template.csv | for each physical test series. Record the date/time, firmware SHA, mode,
direction and track layout, battery voltage/state if measured, parameter intentionally changed, outcome, elapsed time, observed
errors and any reset or repair. Enter | not measured | when an instrument or reliable visual measurement is unavailable rather than
inventing a precision value.

The test layout should record the corridor widths (for Open Challenge), start zone, direction and the positions and signatures of relevant coloured pillars (for Obstacle Challenge). A top-view photo or sketch labelled with the run ID is useful.

## 5.4 Repeatable physical test procedures

### A. Steering and corner tuning

1. Record the deployed values of | Kp , | Kg , | Kd , turn thresholds and 60°/120° steering limits.
2. Check the servo centre and both mechanical end positions with the drive motor disabled.
3. Drive a known straight segment. If measuring drift, identify the reference line, the distance travelled (2 m or 3 m), and the lateral offset at the endpoint in cm.
4. Test clockwise and counter-clockwise 90° corners with identical layout and start speed.
5. For each attempt, note whether the front ToF initiated a turn, whether it exited the turn condition, any wall contact, and any visibly excessive correction.
6. Change only one gain or threshold at a time, keeping a record of the old and new values and of the same test layout. Do not describe an improvement quantitatively unless matched measurements were retained.

### B. Pixy2 signatures and obstacle passing

The team uses signature 1 = green and signature 2 = red. WRO 2026 requires green to be passed on the left and red on the right.

1. In PixyMon verify each of the two trained colour signatures under the lighting used for the test.
2. Place the green and red pillar in turn at known track positions. Record each detected signature and whether the physical pass is on the required side.
3. Repeat from the two track directions where the layout permits.
4. Vary one parameter per series: target image offsets ( -105 | for signature 1 and | 55 | for signature 2), block-height filter, steering
gain ( 0.32 ) or recovery period ( 450 ms ).
5. Note mistaken signatures, missed detections, contacts, side errors and recovery behaviour. A video link and timestamp should be attached for decisive cases.
6. Present an unrelated/untrained Pixy2 signature during a controlled test. Confirm that it is ignored and does not create an obstacle steering command; record the event and firmware SHA.

### C. Three-lap run, stopping and parking status

1. Record the firmware SHA, track layout and start configuration.
2. Attempt three full laps without touching or adjusting the vehicle after the authorised start.
3. Record laps and counted corners, final stopping behaviour, wall/pillar contacts and whether intervention was required.
4. Current status: autonomous parallel parking is not implemented. For an Obstacle Challenge driving run, score the three-
lap/obstacle portion separately and record parking as | not implemented , never | success . If parking is added in a future
firmware revision, separately record whether the parking-space boundaries remain untouched and whether the robot finishes
inside and parallel. The present | FINISHED | state only implements a stop condition.
5. A success fraction is | successful independently documented runs / all independently documented attempts . Keep
failed attempts in the denominator; do not combine incompatible layouts as if they were identical.

### D. Corner-exit watchdog and failure checks

1. With the drive wheels raised and no wall contact possible, verify that a stuck front-ToF corner-exit condition cannot keep the motor running indefinitely; expected code action is motor stop and ERROR after 5000 ms.
2. Repeat normal clockwise and counter-clockwise corners on the actual track, recording entry-to-exit times and whether the watchdog was activated.
3. Treat the fail-safe as implemented but not physically verified until these tests are logged; never report test success solely because the code contains the watchdog.

## 5.5 Metric definitions

Metric | Definition | Source
Straight-line drift (cm) | Lateral endpoint offset after a stated 2 m or 3 m straight | Tape/ruler and reference line
Turn overshoot (cm) | Maximum lateral deviation from the stated intended path after a 90° corner | Marked track / measured video
Obstacle pass success | Correct pass side with no disqualifying contact | Video + run sheet
Three-lap completion | Three complete laps and separately recorded finish behaviour | Video + run sheet
Obstacle recovery (s) | Time from obstacle no longer being detected to normal steering control, using a defined source | Instrumented trace / frame-by-frame video
Reset/timeout count | Number of controller resets or uncompleted turn conditions per run | Serial/event notes
Supply voltage (V) | Measured 5 V line or battery voltage and specified load state | Multimeter / logger

Report n , exact metric, units, setup and spread/range with any average. When a metric cannot be measured, log the observation qualitatively and leave the numeric field blank or mark it unavailable.

## 5.6 Evidence quality and reporting

1. Source-controlled firmware SHA, raw run record, corresponding video with time markers and a documented layout.
2. Dated test notes with measured values and enough setup information to repeat.
3. Historical team summary and observations, which can illustrate development but are not equivalent to a traceable run series.

Preserve the existing validation-summary.csv as a historical summary. Add new physical results with their own source evidence and do not overwrite older values to make the trend look smoother.

The retained historical CSV remains linked as a numerical supporting file, while the result interpretation and the measurement protocol are fully explained in this README. A future physical test may improve the confidence in the reported estimates; documentation alone cannot supply missing measurements.

# 6. Robot evolution

We kept older photos to show how the design changed.

## Stage 1: earlier full vehicle

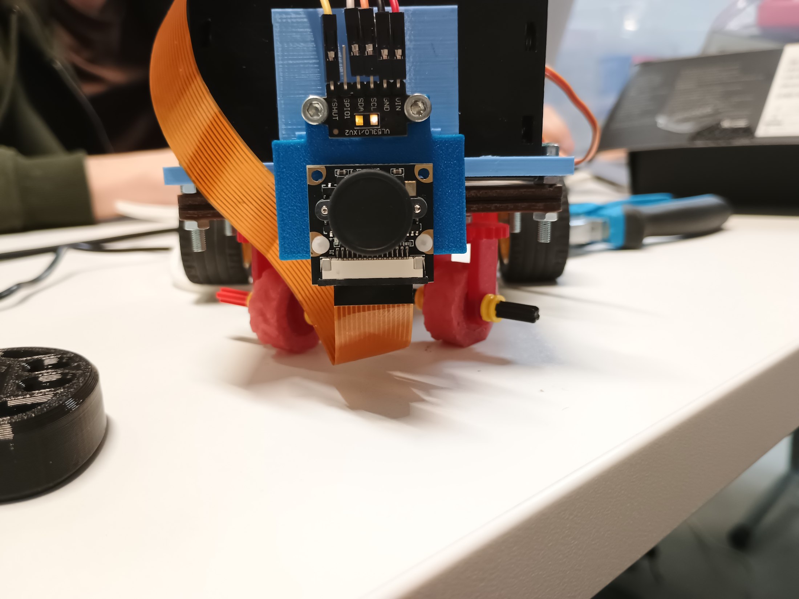
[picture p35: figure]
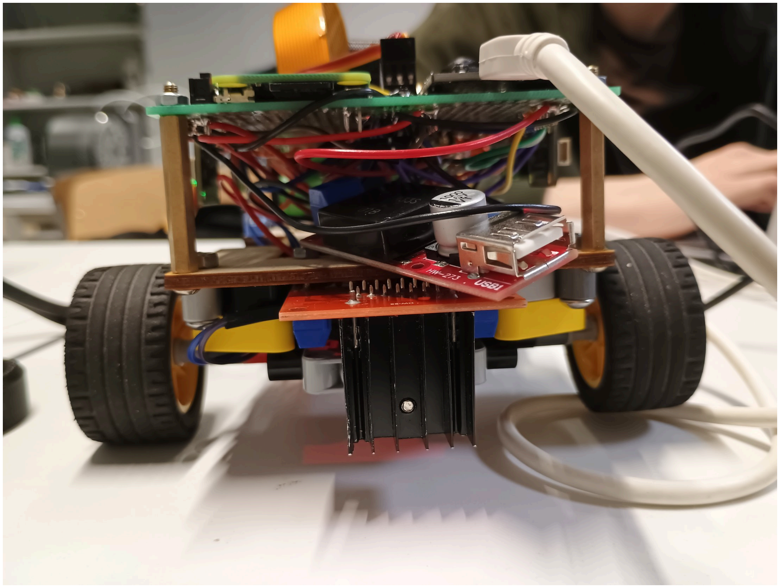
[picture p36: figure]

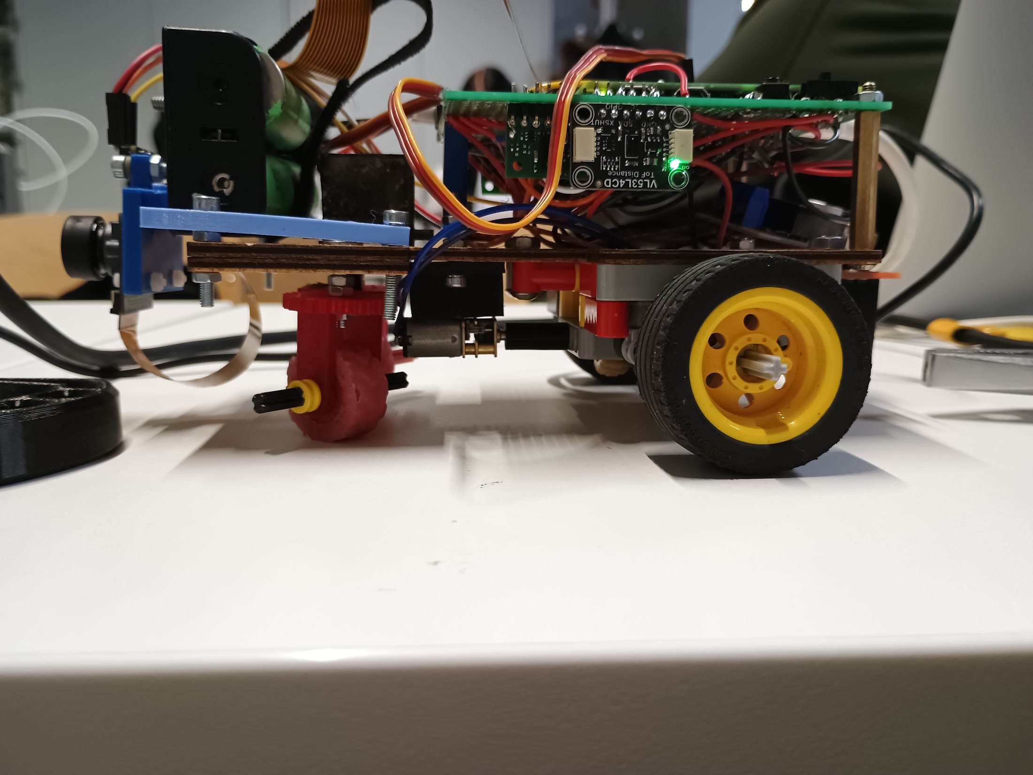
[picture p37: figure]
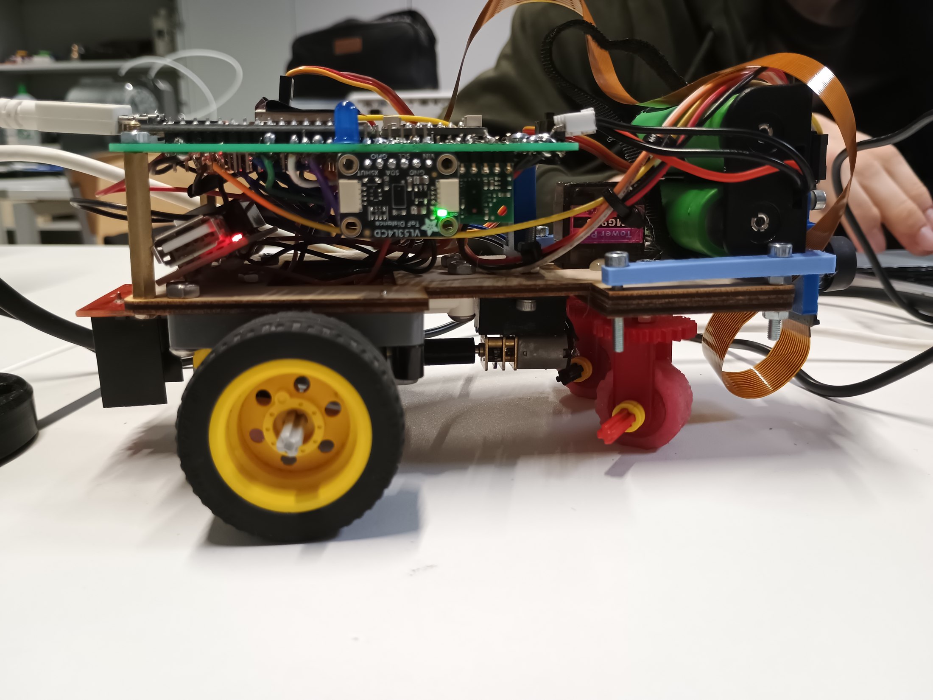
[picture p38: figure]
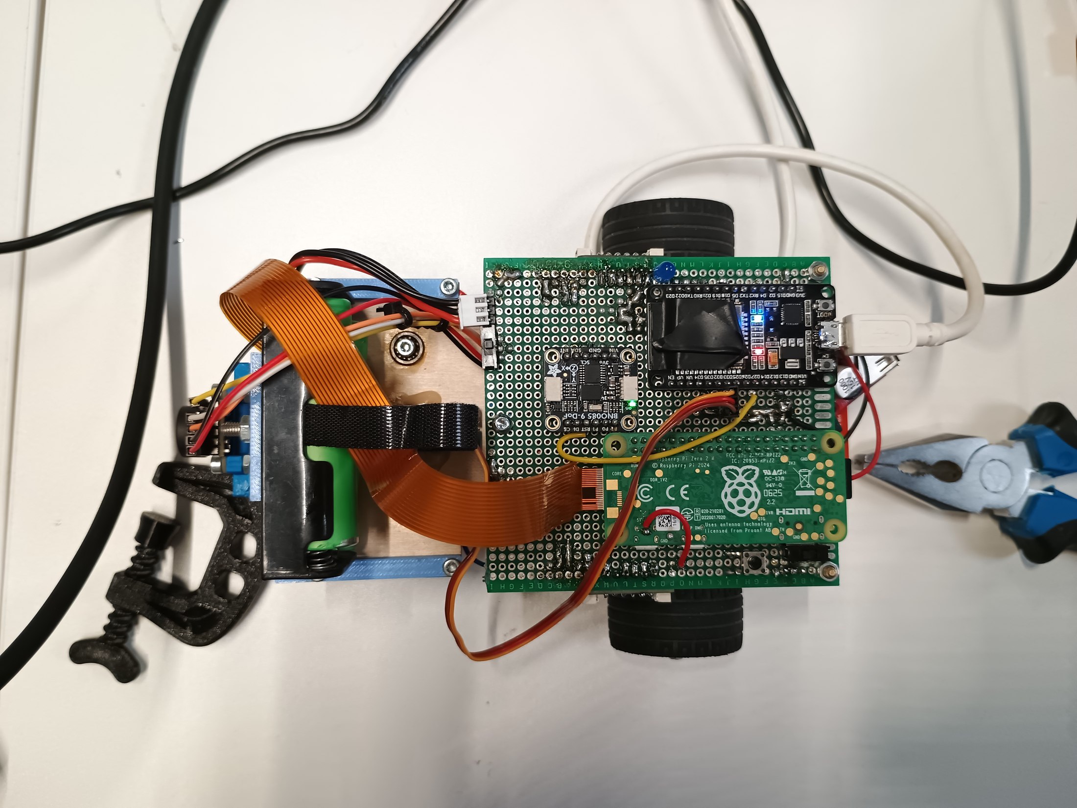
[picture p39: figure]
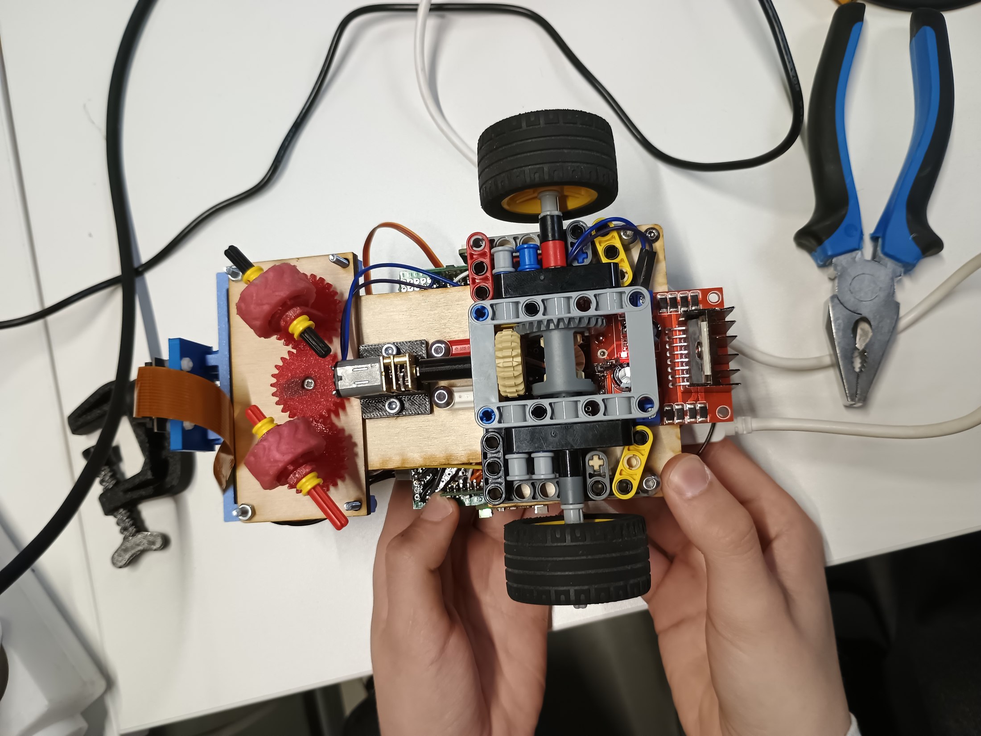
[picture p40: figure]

This is the earlier packaging baseline. The later car is smaller and uses less hardware.

## Stage 2: differential and drivetrain

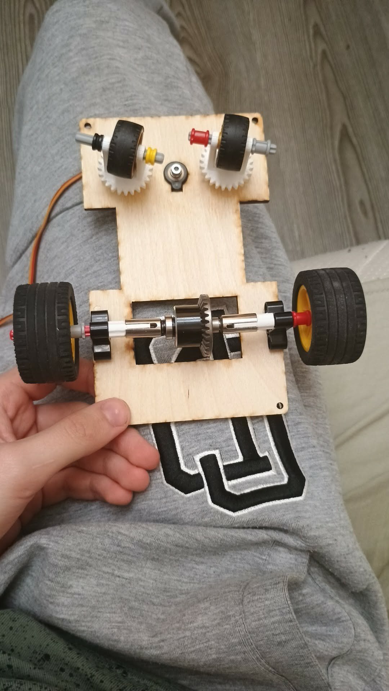
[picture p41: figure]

## Stage 3: steering

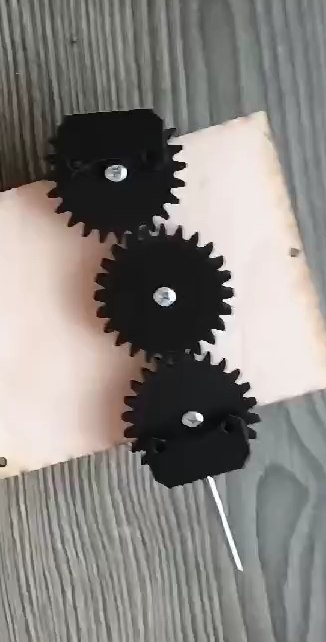
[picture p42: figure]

## Stage 4: electronics integration

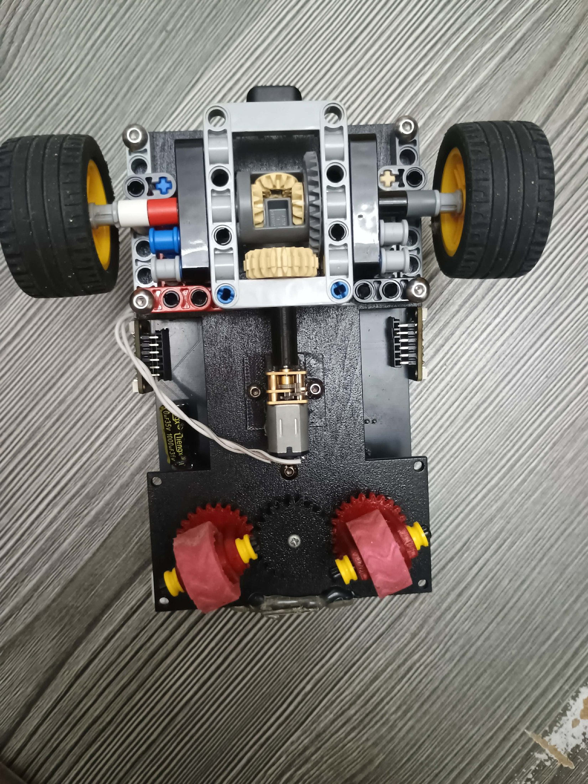
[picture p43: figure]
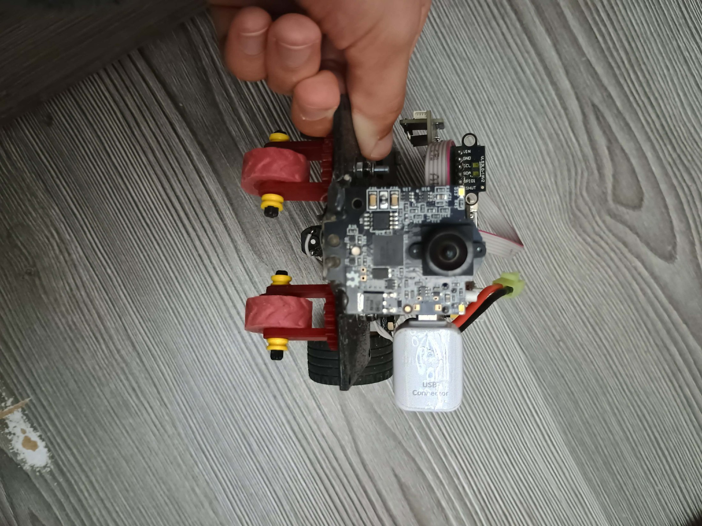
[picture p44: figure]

## Stage 5: final competition robot

The five photos near the top show the final robot with the black PCB and white rear wheels.

# 7. Bill of materials and sourcing

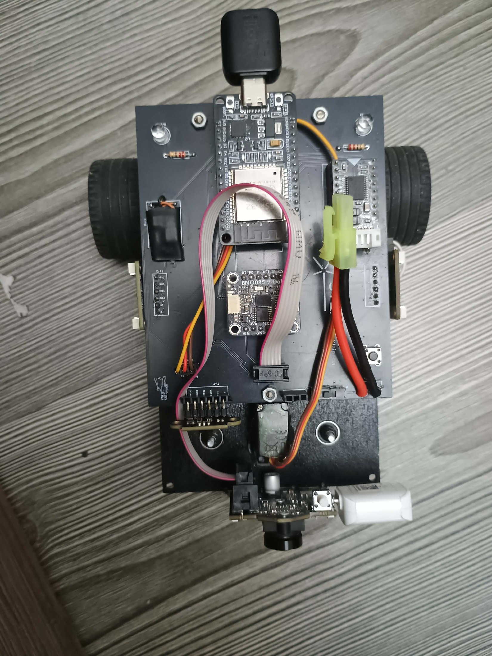
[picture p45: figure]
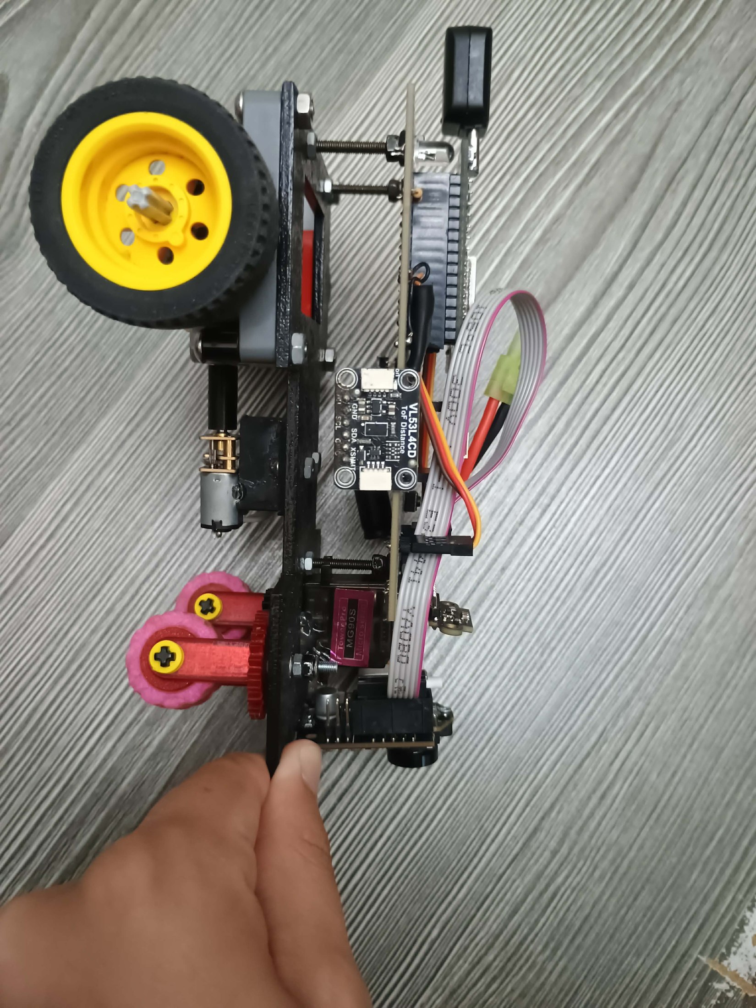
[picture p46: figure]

The supplier links are examples. Match each part to the model, footprint and electrical or mechanical interface listed here.

Qt y | Component | Final specification | Example source | Important detail
1 | ESP32 board | ESP32-WROOM-32 DevKit V1, 30 pin | 3DSVET EU (https://www.3dsvet.eu/izdelek/esp32-wroom32-30pinov-microusb/) | 38-pin boards do not fit the same PCB footprint
1 | IMU | Adafruit BNO085, product 4754 | Adafruit (https://www.adafruit.com/product/4754) | fixed chassis orientation
3 | ToF sensor | VL53L1X on 6-pin carrier | Pololu (https://www.pololu.com/product/3415) | the sensor itself must be VL53L1X, even if the carrier looks similar
1 | Camera | Pixy2 / Pixy2.1 CMUcam5 | RobotShop EU (https://eu.robotshop.com/products/charmed-labs-pixy-21-robot-vision-image-sensor-rbc) | direct ESP32 SPI connection through the custom PCB
1 | Steering servo | TowerPro MG90S positional | Anodas LT (https://www.anodas.lt/en/towerpro-mg90s-micro-analog-servo-with-metal-gear) | do not use 360° continuous rotation
1 | Motor driver | Makeblock MegaPi Encoder/DC Motor Driver V1 | BerryBase (https://www.berry-base.com/makeblock-megapi-encoder-dc-motor-driver-v1-2-kanaele-6-12-v-3-a-nennstrom-5-5-a-peak) | brushed DC output used
1 | Drive motor | N20, 6 V, nominal 600 rpm, 3 mm D-shaft class | HESTORE (https://www.hestore.eu/prod_10042830.html) | check shaft length before ordering
1 | Battery | 2S LiPo, 7.4 V, 2500 mAh, 30C | RC supplier | must fit final packaging
1 | 5 V regulator | Matek Micro BEC 6S, 6–30 V input, 5 V/9 V adjustable | RCdalys (https://www.rcdalys.lt/detales/0/27234/MATEK-MICRO-BEC-6S-6-30V-5V9V-ADJUSTABLE-3PCS) | set to 5 V; 1.5 A continuous, 2.5 A max for 5 s/min

Qt y | Component | Final specification | Example source | Important detail
1 | PCB | KU STEAM Pinkies final board | schemes/ Gerbers | manufacture from the checked-in package
1 | Rear differential | LEGO-compatible differential | LEGO/Technic source | geometry must match final drivetrain
2 | Rear wheels | final white custom wheel geometry | models/ | use final wheel CAD/material
2 | Front wheel/steering assemblies | final printed/LEGO-compatible geometry | models/ | do not scale STL files
1 | Plywood base | final cut vector | models/case.a i | import at 1:1 scale

### Replacement rules

ESP32 replacements must keep the same 30-pin footprint and required GPIOs.
ToF replacements must use VL53L1X and expose XSHUT.
Servo must be positional, not continuous rotation.
The 5 V regulator must meet the final Matek Micro BEC 6S electrical role: 2S-compatible input and enough continuous current for the documented 5 V load.
N20 replacements must match voltage, speed class and shaft geometry.
Mechanical substitutions must preserve axle, hole and wheel geometry.
Treat any change to the pinout, sensor type, wheel size, steering geometry or camera interface as a new robot revision, and retest the robot.

# 8. Rebuilding the robot

Use the CAD files and steps below to rebuild the robot. Use the photos as visual references, not for measuring dimensions.

## Mechanics

1. Cut the base from models/case.ai .
2. Print the final STLs from models/ without scaling.
3. Assemble the rear motor, gear stage, differential and wheels.
4. Assemble the front steering parts and MG90S.
5. Centre the linkage and verify the command range from 60° to 120°.

## Electronics

1. Manufacture the PCB from the schemes/ Gerber/drill package.
2. Install the 30-pin ESP32 board.
3. Connect BNO085 and the three VL53L1X modules to I2C.
4. Connect XSHUT to GPIO15 / GPIO5 / GPIO18 for front / left / right.
5. Connect MG90S to GPIO33.
6. Connect the motor driver to GPIO26, GPIO25 and GPIO32.
7. Connect Pixy2 to the final board's SPI camera connector; the PCB routes MOSI , MISO , SCK , 5 V and GND to the camera header.
8. Check ground and supply polarity before applying motor power.

## Firmware

platformio run -d src -e open_challenge

platformio run -d src -e obstacle_challenge

Upload the build for the required challenge, then run the calibration checks in section 2.6.

## Final acceptance checks

base and printed parts match the final CAD revision;
drivetrain turns freely;
steering is centred and does not bind; front/left/right ToF identities match 0x30/0x31/0x32 ;

BNO085 heading direction is correct;
Pixy2 image direction matches steering logic;
ESP32 does not reset during hard steering and acceleration;
only trained Pixy2 signatures 1/2 influence obstacle steering (regression test still required);
the corner-exit watchdog ends a stuck turn without ongoing motor power (physical validation still required); both PlatformIO environments compile;
Open Challenge straight/corner control runs without manual input;
Obstacle Challenge recognises the trained signatures, passes and recovers to normal driving;
parallel parking is not yet implemented; do not record the entire 2026 Obstacle Challenge as complete.

# 9. Repository layout

README.md | project engineering journal
src/ | ESP32 PlatformIO firmware
models/ | final STL/CAD + case.ai base vector
schemes/ | schematic images, PCB PDF, Gerbers and drill files
videos/ | competition run recordings
v-photos/ | final robot photographs
t-photos/ | team photograph
docs/design/images/ | drivetrain and steering development photos
docs/design/history/ | earlier whole-robot photographs
docs/report/images/ | build/electronics development photographs
docs/testing/ | retained validation CSV and raw-run template

This README is the single engineering-journal and assessment narrative: technical rationale, methods, results, limitations, reconstruction, testing procedures and version notes are readable here without opening another Markdown document. Source code, CAD, PCB files, CSVs, photos and videos stay in their original formats as linked supporting evidence. Build verification is manual;
there is intentionally no GitHub Actions CI or | scripts/ | verification directory in the current repository.

# 10. Versioning and verification record

This section records the competition-ready documentation state of the robot and the workflow used to keep hardware, firmware and validation evidence aligned. Git commit history provides the detailed change-by-change record, while this section identifies the current documented revision and the checks expected after material changes.

## Current competition revision

The documented competition configuration uses:

ESP32-WROOM-32, 30-pin DevKit V1 form factor;
BNO085 heading sensor;
3 × VL53L1X distance sensors in Long mode;
Pixy2 / Pixy2.1 vision connected directly to ESP32 over SPI; N20 6 V motor, nominal 600 rpm;
LEGO-compatible gearing and rear differential;
MG90S positional steering servo;
2S LiPo, 7.4 V, 2500 mAh, 30C;
custom PCB;
approximate overall size of 165 × 145 × 70 mm;
documented mass of 332.4 g.

The firmware is maintained as one source tree with two explicit PlatformIO environments. The currently documented Obstacle build has pillar avoidance and finish stopping, but no autonomous parallel-parking routine:

platformio run -d src -e open_challenge

platformio run -d src -e obstacle_challenge

open_challenge | uses | WRO_CHALLENGE_MODE=0 ;
obstacle_challenge | uses | WRO_CHALLENGE_MODE=1 .

## Reproducibility package

The repository keeps the material needed to rebuild, inspect and validate the documented robot in version control:

README.md | — design reasoning, architecture, calibration, tuning, rebuild instructions and this versioning record;
src/ | — ESP32 PlatformIO firmware;
models/ | — final STL/CAD files and | case.ai ;
schemes/ | — PCB documentation, Gerbers, drill files and schematic images;
docs/testing/validation-summary.csv | — retained validation summary;
docs/testing/raw/run-template.csv | — repeatable run-record format;
README.md | section 5 — the full test protocol, metric definitions, evidence requirements and historical result context;
v-photos/ | — final robot photographs;
t-photos/ | — team photograph;
videos/ | — competition run recordings.

## Verification workflow for a material revision

When a material robot revision is made:

1. record the Git commit SHA used for the revision;
2. build both PlatformIO environments;
3. repeat the calibration checks in section 2.6;
4. repeat the final acceptance checks in section 8;
5. record new physical runs using | docs/testing/raw/run-template.csv ;
6. update | docs/testing/validation-summary.csv | from retained measurements;
7. document what changed, why it changed and which subsystem was affected.

A change to pinout, sensor type, wheel size, steering geometry, camera interface or challenge-control behaviour is treated as a new robot revision and is rechecked before its results are used as final competition evidence.

## Revision trace

The Git history provides the detailed evolution of the project. Meaningful commits cover the major documented revisions, including chassis and drivetrain development, steering redesign, sensor architecture changes, custom PCB integration, Pixy2 SPI correction, testing workflow updates and final power/sensor/calibration documentation. Together with the robot-evolution section and retained test results, this provides traceability from earlier prototypes to the current competition configuration.

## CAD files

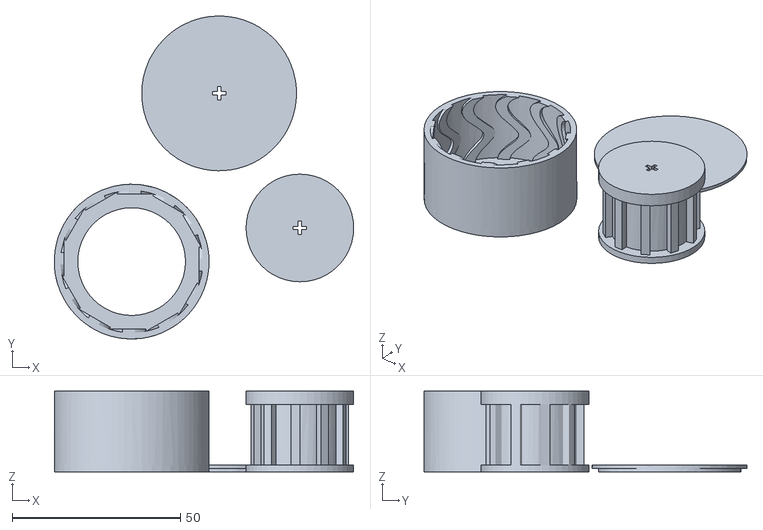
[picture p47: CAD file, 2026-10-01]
models/Rear_wheel_mold.stl
89.0 x 96.0 x 24.0

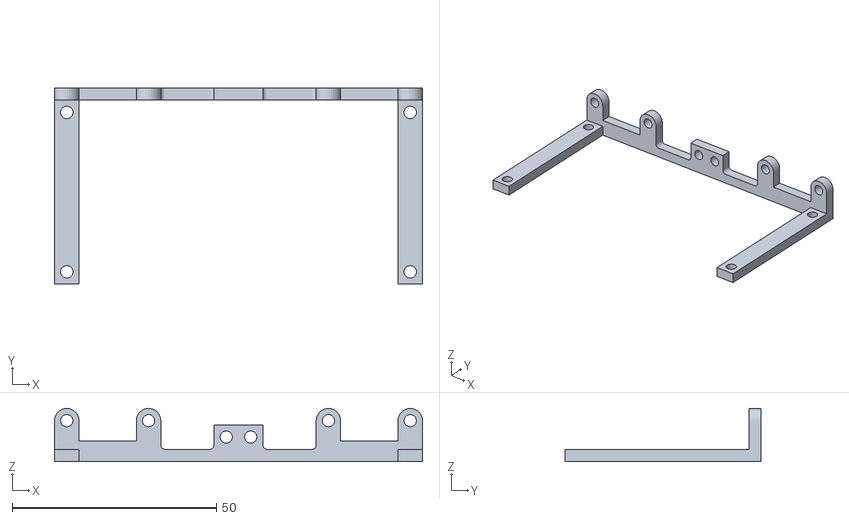
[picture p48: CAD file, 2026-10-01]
models/Front.stl
90.0 x 48.0 x 13.0

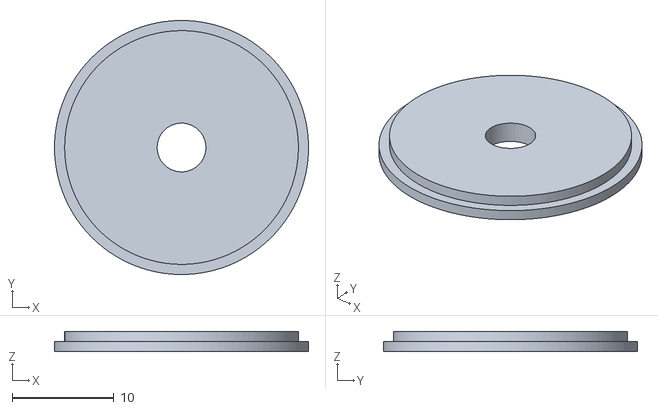
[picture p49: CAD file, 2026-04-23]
models/Front_wheel_mold.stl
25.0 x 25.0 x 2.00

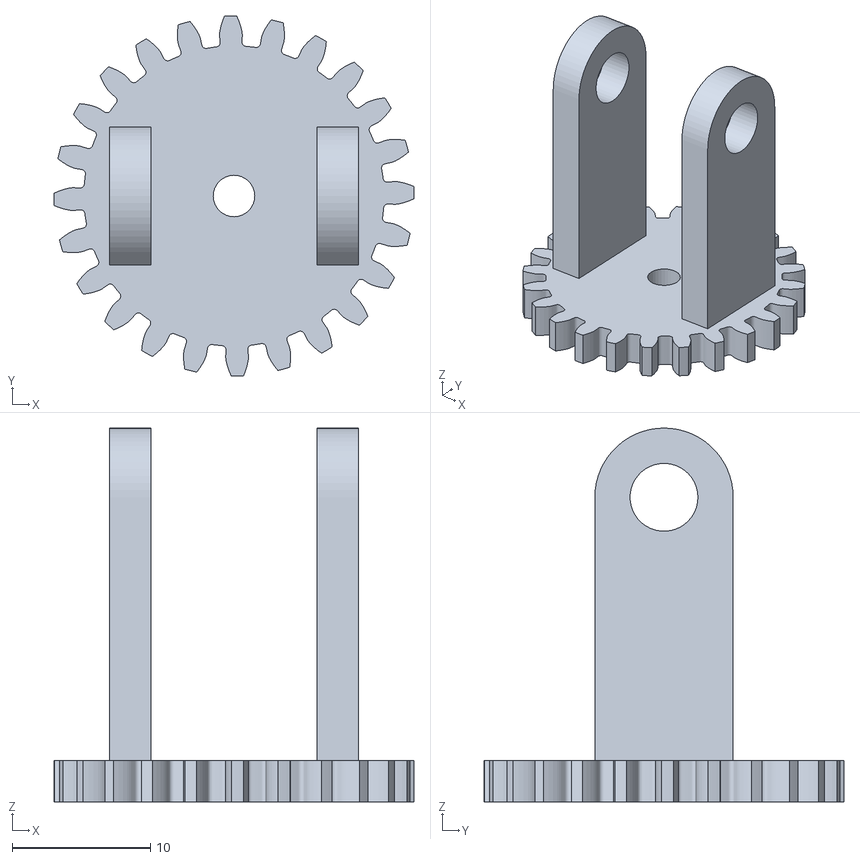
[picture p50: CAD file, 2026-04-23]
models/Front_wheel_gear.stl
26.0 x 26.0 x 27.0

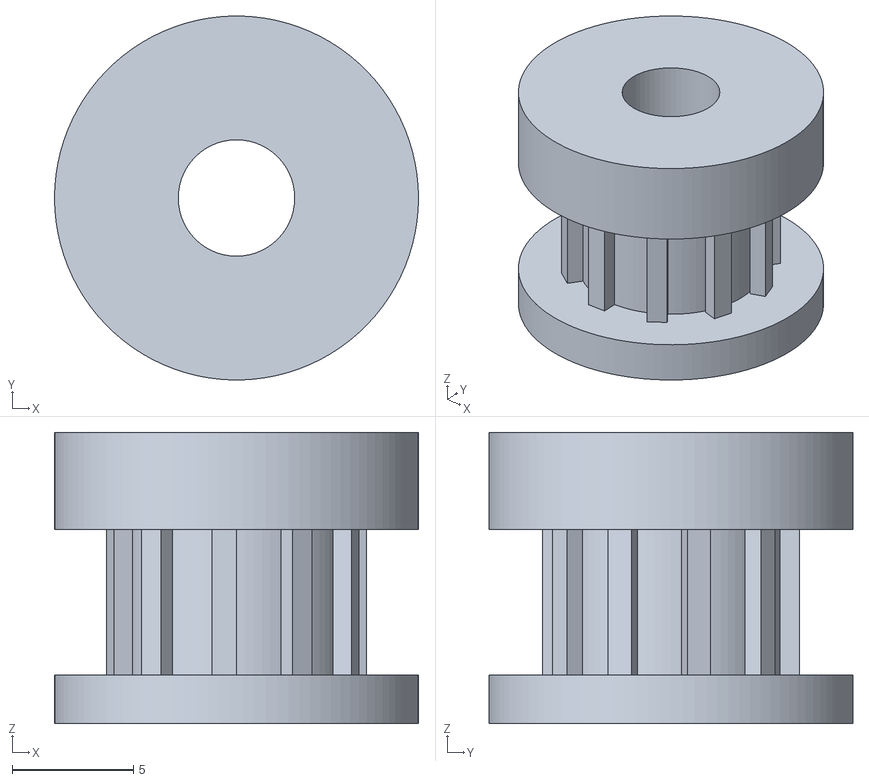
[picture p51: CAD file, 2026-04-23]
models/Front_wheel.stl
15.0 x 15.0 x 12.0

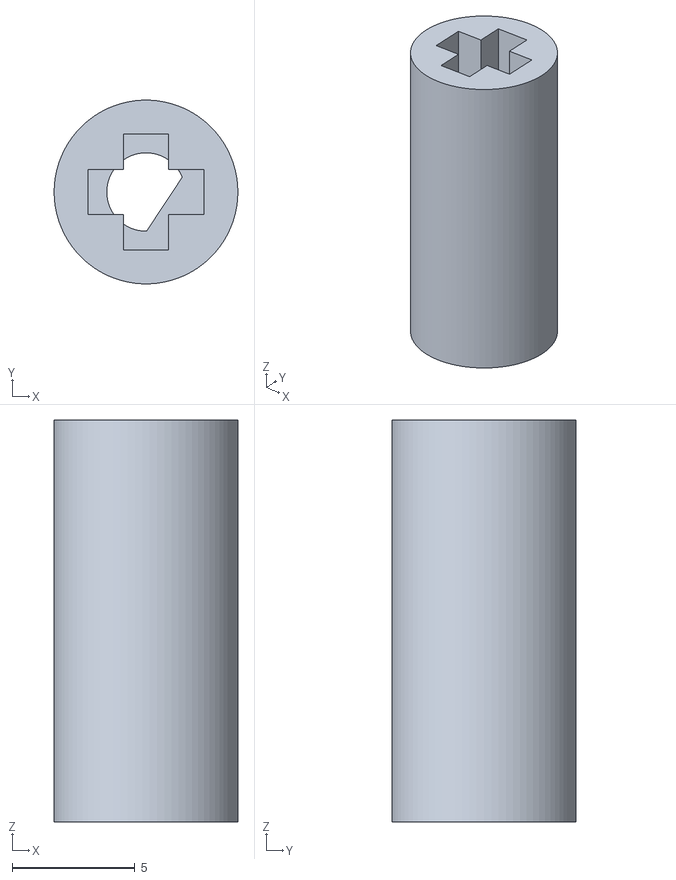
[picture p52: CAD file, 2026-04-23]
models/Motor_adapter.stl
7.50 x 7.49 x 16.4

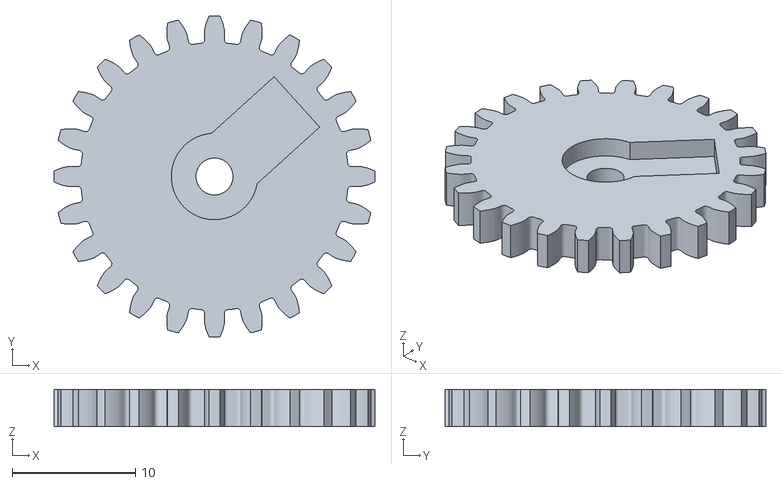
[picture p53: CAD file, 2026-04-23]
models/middle_gear_steering.stl
26.0 x 26.0 x 3.00

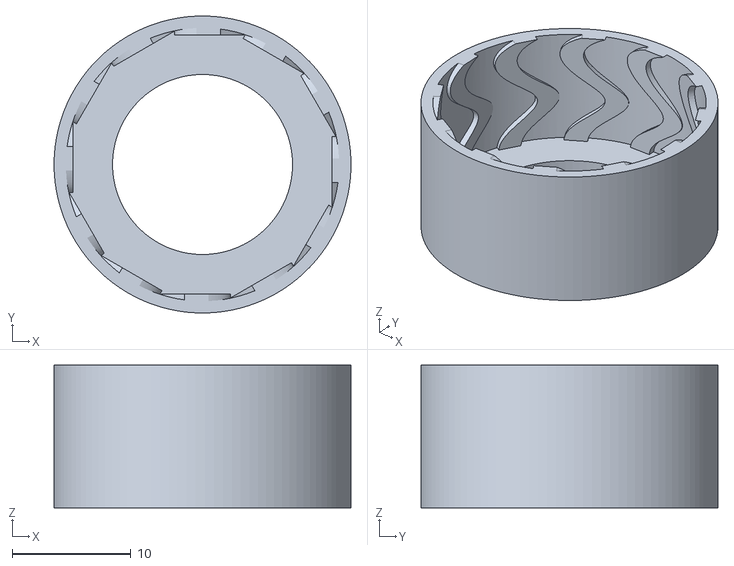
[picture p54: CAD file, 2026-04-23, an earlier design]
models/Front_wheel_mold(1).stl
25.0 x 25.0 x 12.0

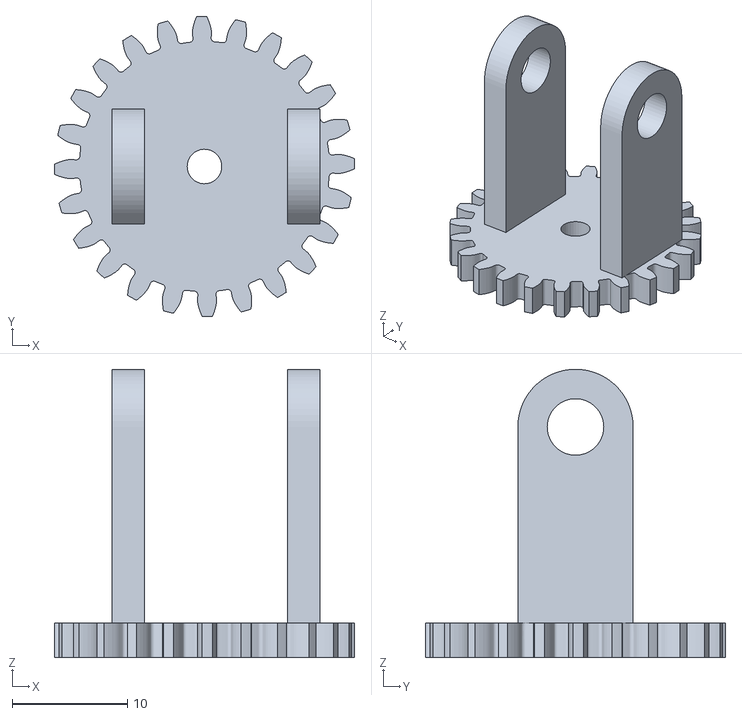
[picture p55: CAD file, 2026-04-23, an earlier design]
models/Front_wheel_gear(1).stl
26.0 x 26.0 x 25.0

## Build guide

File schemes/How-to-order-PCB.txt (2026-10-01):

How to Order PCB

PCB ordering instructions are on this EasyEDA page:
https://prodocs.easyeda.com/en/pcb/order-order-pcb/index.html

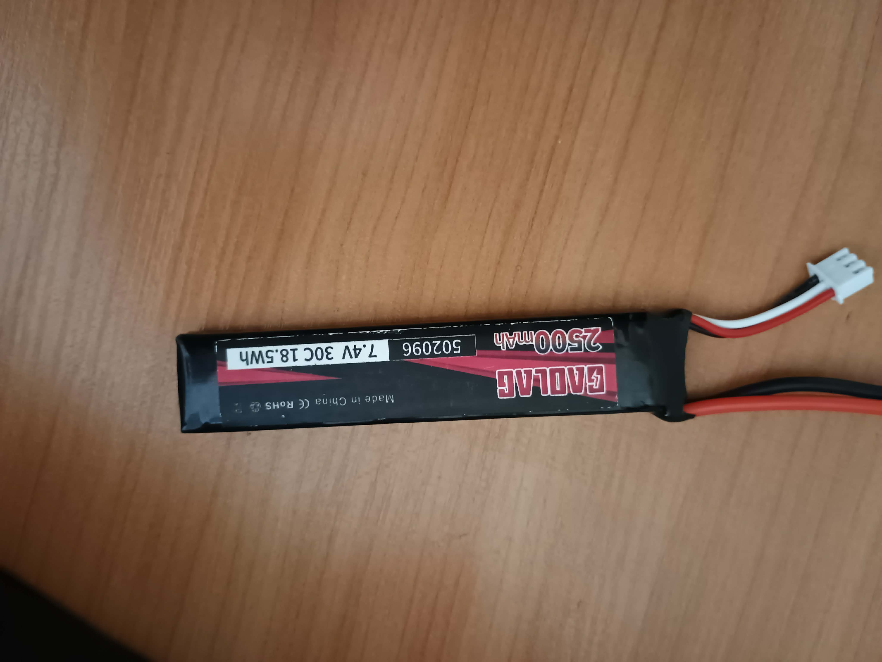
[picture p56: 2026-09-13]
docs/report/images/build-context/battery.jpeg

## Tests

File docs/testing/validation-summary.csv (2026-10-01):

metric | earlier_version | updated_version | sample_or_scope | notes | evidence_class
straight_corridor_drift_after_2m_cm | 9 | 4 | 10 runs | team-reported comparison | team_reported
successful_3_lap_runs | 6/10 | 9/10 | 10 attempts per version | repeatability comparison | team_reported
corner_overshoot_cm | 14 | 6 | summary observation | no matched raw dataset retained | summary_observation
obstacle_recovery_s | 1.2 | 0.6 | summary observation | no matched raw dataset retained | summary_observation
strict_3m_drift_run_1_cm | 11 | 4 | matched five-run comparison |  | matched_run_values
strict_3m_drift_run_2_cm | 10 | 5 | matched five-run comparison |  | matched_run_values
strict_3m_drift_run_3_cm | 12 | 3 | matched five-run comparison |  | matched_run_values
strict_3m_drift_run_4_cm | 9 | 4 | matched five-run comparison |  | matched_run_values
strict_3m_drift_run_5_cm | 11 | 4 | matched five-run comparison |  | matched_run_values
strict_3m_drift_average_cm | 10.6 | 4.0 | 5 runs per version | 6.6 cm reduction (~62%); run-level values retained in this CSV but original firmware/date metadata not retained | matched_run_values
open_straight_success |  | 5/5 | final validation layout | no matched earlier baseline recorded | final_layout_result
obstacle_slalom_success |  | 4/5 | final validation layout | no matched earlier baseline recorded | final_layout_result
full_practice_route_success |  | 4/5 | final validation layout | no matched earlier baseline recorded | final_layout_result
turning_space_90deg_cm | 46 | 39 | summary observation | sample count not recorded | summary_observation

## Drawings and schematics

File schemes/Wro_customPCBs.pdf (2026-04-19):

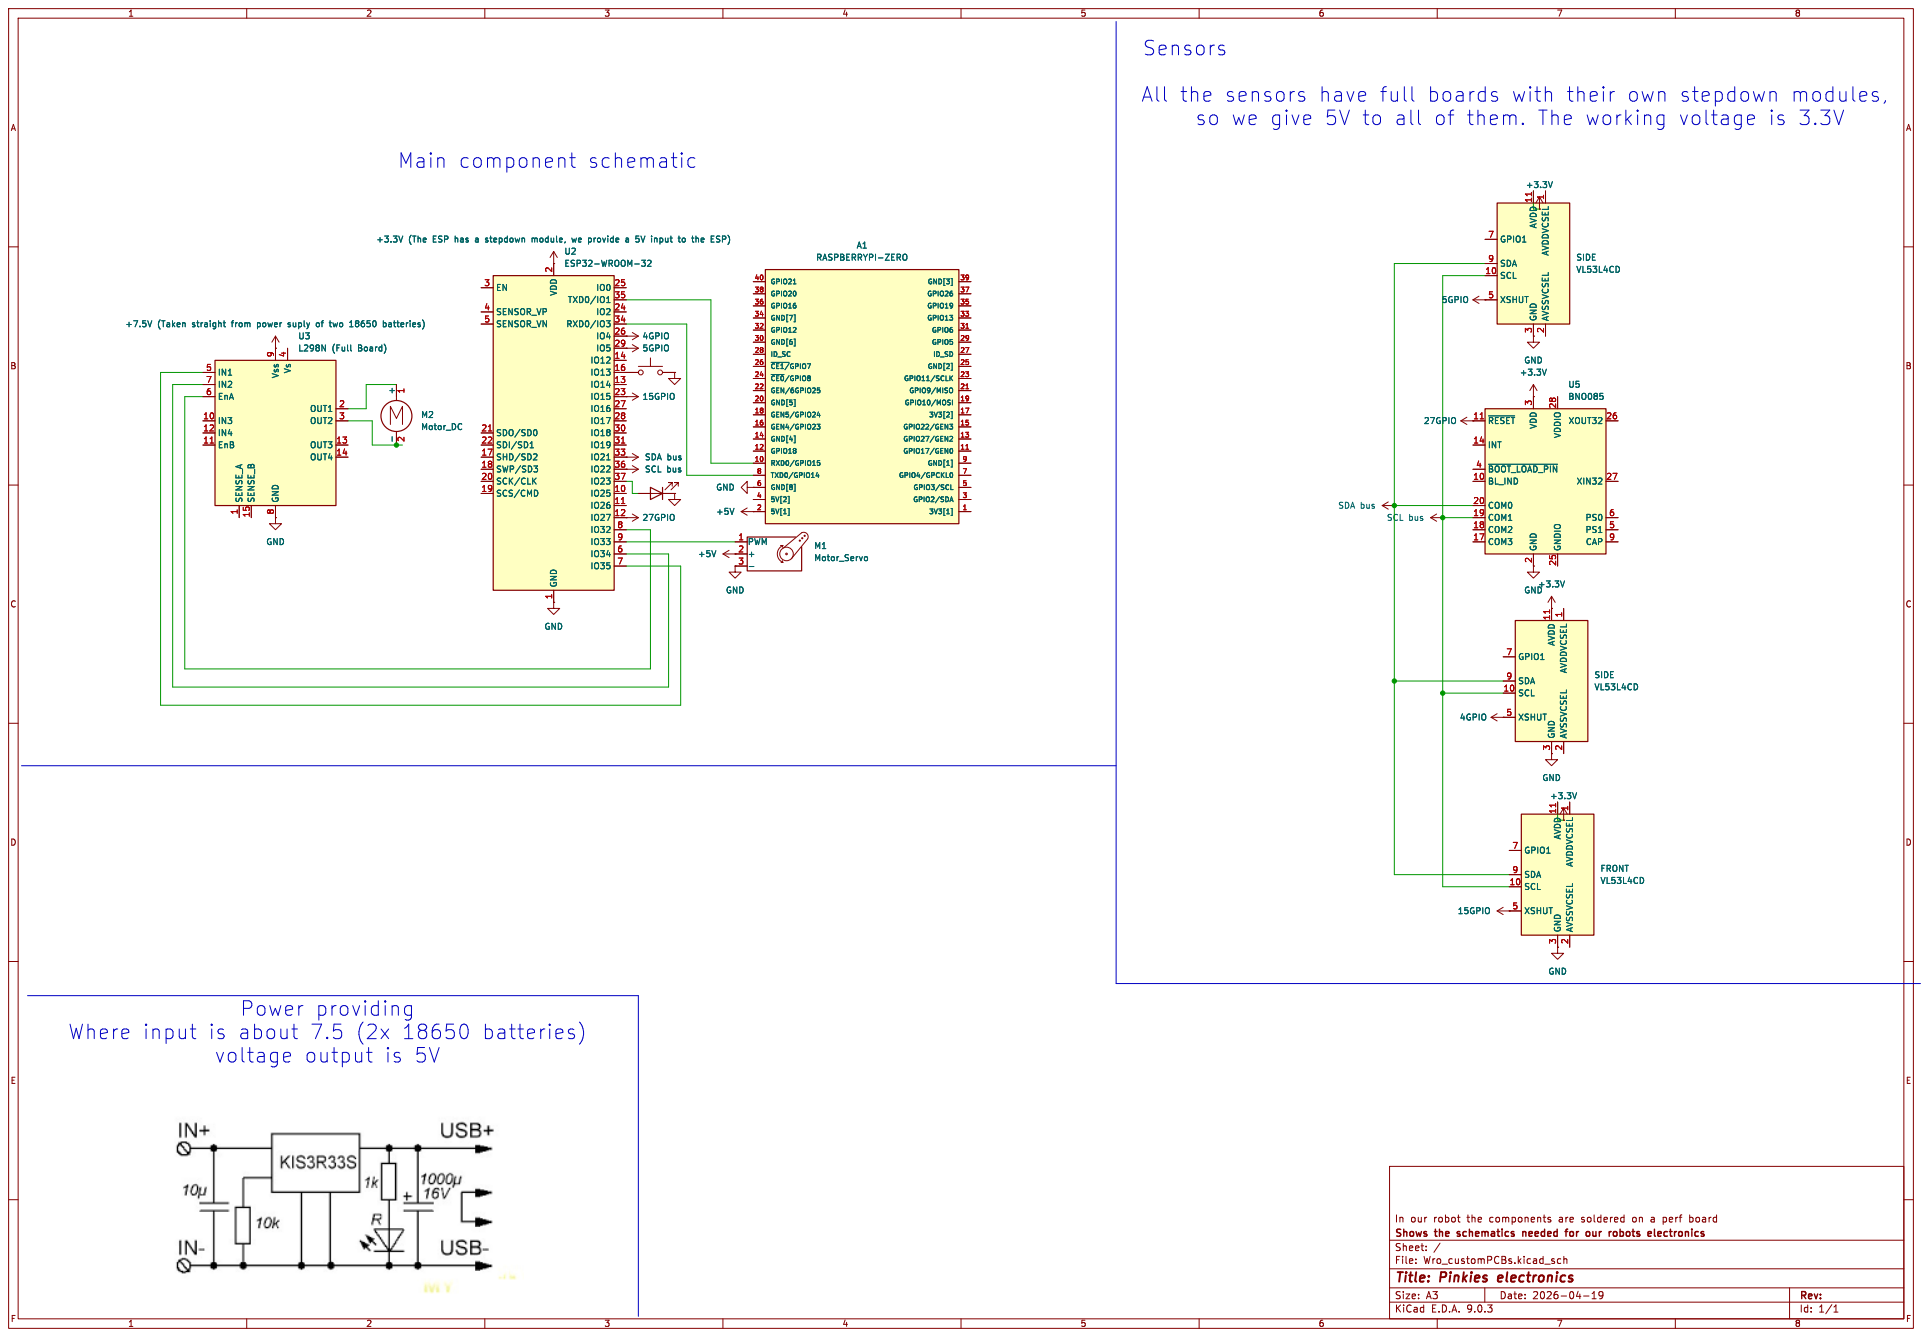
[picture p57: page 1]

All the sensors have full boards with their own stepdown modules,
so we give 5V to all of them. The working voltage is 3.3V

+3.3V (The ESP has a stepdown module, we provide a 5V input to the ESP) 15GPIO

+3.3V (The ESP has a stepdown module, we provide a 5V input to the ESP)

2 VDDIO 28 GNDIO 25 XOUT32 26 XIN32 27 PS0 6 PS1 5 CAP 9 GND

Where input is about 7.5 (2x 18650 batteries)

Id: 1/1 Title: Pinkies electronics

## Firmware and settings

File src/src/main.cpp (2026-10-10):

#include <Arduino.h>
#include <Lights.h>
#include <Lidar.h>
#include <Engine.h>
#include <Compass.h>
#include <ESP32Servo.h>
#include <Wire.h>
#include <Pixy2.h>
#include <CompetitionMode.h>

// Hardware / control constants
const int BUTTON_PIN = 14;
const int ENABLE_MOTOR = 32;
const int MOTOR_1 = 26;
const int MOTOR_2 = 25;
const int ROBOT_WIDTH = 150;
const int MIN_ANGLE = 60;
const int MAX_ANGLE = 120;
const int STRAIGHT_ANGLE = 88;
const int TARGET_DISTANCE = 300;
const int WIDTH_THRESHOLD = 150;

// Obstacle-vision tuning
const int PIXY_MIN_BLOCK_HEIGHT = 8;
const int PIXY_MAX_BLOCK_HEIGHT = 70;
const int PIXY_SIGNATURE_1_OFFSET = -105;
const int PIXY_SIGNATURE_2_OFFSET = 55;
const float PIXY_STEERING_GAIN = 0.32;
const unsigned long OBSTACLE_RECOVERY_MS = 450;
// Fail-safe only: stop if a corner-exit condition cannot be reached.
const unsigned long CORNER_EXIT_TIMEOUT_MS = 5000;

// PPD constants
const float Kp = 0.09;
const float Kg = 0.95;
const float Kd = 0.05;

enum class RobotState : uint8_t {
  WAIT_FOR_START,
  NORMAL_DRIVING,
  TURNING,
  OBSTACLE_AVOIDANCE,
  OBSTACLE_RECOVERY,
  FINISHED,
  ERROR
};

RobotState robotState = RobotState::WAIT_FOR_START;

// Global variables
float last_error = 0;
float last_time = 0;
float targetAngle = 0;
int edge = 0;
bool isClockwise = true;
bool sideLock = false;
int sectorWidth[4] = {0};
int cumulativeWidth = 0;
int measurementCount = 0;
unsigned long clockStop = 0;
bool button_state = 1;
unsigned long obstacleRecoveryUntil = 0;

auto engine = Engine(MOTOR_1, MOTOR_2, ENABLE_MOTOR);
Compass robotCompass;
Servo myservo;
Distance_Sensor leftSensor;
Distance_Sensor rightSensor;
Distance_Sensor frontSensor;
Pixy2 pixy;

void setRobotState(RobotState nextState) {
  robotState = nextState;
}

void resetRunTracking() {
  last_error = 0;
  last_time = 0;
  edge = 0;
  isClockwise = true;
  sideLock = false;
  for (int i = 0; i < 4; i++) {
    sectorWidth[i] = 0;
  }
  cumulativeWidth = 0;
  measurementCount = 0;
  clockStop = 0;
  obstacleRecoveryUntil = 0;
}

void failStartup(const char* message) {
  Serial.println(message);
  setRobotState(RobotState::ERROR);
  while (1) {
    delay(100);
  }
}

void setup() {
  Serial.begin(115200);
  Wire.begin();

  set_light_state(2, 0);
  pinMode(BUTTON_PIN, INPUT_PULLUP);

  pinMode(MOTOR_1, OUTPUT);
  pinMode(MOTOR_2, OUTPUT);
  pinMode(ENABLE_MOTOR, OUTPUT);

  // Keep all three identical-address VL53L1X sensors disabled, then
  // initialize them one-by-one and assign unique I2C addresses.
  pinMode(5, OUTPUT);
  pinMode(18, OUTPUT);
  pinMode(15, OUTPUT);
  digitalWrite(5, LOW);
  digitalWrite(18, LOW);
  digitalWrite(15, LOW);
  delay(50);

  if (!frontSensor.begin(15, 0x30)) {
    failStartup("Front ToF failed!");
  }

  delay(50);

  if (!leftSensor.begin(5, 0x31)) {
    failStartup("Left ToF failed!");
  }

  delay(50);

  if (!rightSensor.begin(18, 0x32)) {
    failStartup("Right ToF failed!");
  }

  if (!robotCompass.begin()) {
    failStartup("Compass failed!");
  }

  ledcSetup(0, 30000, 8);
  ledcAttachPin(ENABLE_MOTOR, 0);
  engine.begin();

  myservo.attach(33, 500, 2400);
  myservo.write(STRAIGHT_ANGLE);
  set_light_state(2, 3);

  // Pixy2 performs CCC processing and is read directly by the ESP32.
  pixy.init();
  pixy.setLamp(1, 0);
  pixy.setLED(0, 0, 0);

  setRobotState(RobotState::WAIT_FOR_START);
}

void loop() {
  button_state = digitalRead(BUTTON_PIN);
  blink_lights();

  if (button_state == 0) {
    delay(400);
    if (robotState == RobotState::WAIT_FOR_START || robotState == RobotState::FINISHED) {
      resetRunTracking();
      targetAngle = robotCompass.getYaw();
      setRobotState(RobotState::NORMAL_DRIVING);
    } else if (robotState != RobotState::ERROR) {
      setRobotState(RobotState::WAIT_FOR_START);
    }
  }

  // States that require no driving are handled immediately. The remaining
  // states continue into the shared sensing/control section below.
  switch (robotState) {
    case RobotState::WAIT_FOR_START:
      set_light_state(2, 3);
      engine.stop();
      return;

    case RobotState::FINISHED:
      set_light_state(2, 3);
      engine.stop();
      return;

    case RobotState::ERROR:
      set_light_state(2, 0);
      engine.stop();
      return;

    case RobotState::NORMAL_DRIVING:
    case RobotState::TURNING:
    case RobotState::OBSTACLE_AVOIDANCE:
    case RobotState::OBSTACLE_RECOVERY:
      break;
  }

  set_light_state(2, 1);
  engine.drive(255);

  // Direct Pixy2 -> ESP32 obstacle data.
  pixy.ccc.getBlocks();

  float heading = targetAngle - robotCompass.getYaw();
  if (heading > 180) heading -= 360;
  if (heading < -180) heading += 360;

  Distance_Result frontDistance = frontSensor.measureDistance();
  const Distance_Result leftDistance = leftSensor.measureDistance();
  const Distance_Result rightDistance = rightSensor.measureDistance();
  const int width = leftDistance.distance + rightDistance.distance;
  const int currentSector = abs(targetAngle) / 90;
  int nextSector = currentSector + 1;
  if (nextSector == 4) {
    nextSector = 0;
  }

  Serial.println(String("L: ") + leftDistance.distance + "mm (" + leftDistance.status + ") R: "
    + rightDistance.distance + "(" + rightDistance.status + ") Gyro: " + heading + " Front: "
    + frontDistance.distance + "mm (" + frontDistance.status + ") Sector: " + currentSector
    + " Width: " + sectorWidth[currentSector] + " Next: " + nextSector);

  const bool cornerDetected =
    frontDistance.distance <= (ROBOT_WIDTH + (sectorWidth[nextSector] == 0 ? TARGET_DISTANCE : (sectorWidth[nextSector] / 2)))
    && frontDistance.status == 0
    && width >= 900;

  if (cornerDetected) {
    setRobotState(RobotState::TURNING);

    if (!sideLock) {
      isClockwise = (leftDistance.distance <= 700 && (leftDistance.status == 0 || leftDistance.status == 2));
      sideLock = true;
    }

    if (!OBSTACLE_ROUND && measurementCount > 0) {
      sectorWidth[currentSector] = constrain(cumulativeWidth / measurementCount, 500, 900);
    }

    const unsigned long cornerStartedAt = millis();
    while (frontDistance.distance <= 1500 || frontDistance.distance >= 2700 || frontDistance.status == 4) {
      if (millis() - cornerStartedAt >= CORNER_EXIT_TIMEOUT_MS) {
        // Never drive indefinitely when a ranging/turn-exit condition is stuck.
        Serial.println("Corner exit timeout: motor stopped; check front ToF and steering.");
        engine.stop();
        setRobotState(RobotState::ERROR);
        return;
      }
      frontDistance = frontSensor.measureDistance();
      myservo.write(isClockwise ? MIN_ANGLE : MAX_ANGLE);
      delay(20);
    }

    targetAngle += isClockwise ? -90 : 90;
    targetAngle = fmod(targetAngle, 360.0);
    edge++;
    cumulativeWidth = 0;
    measurementCount = 0;
    setRobotState(RobotState::NORMAL_DRIVING);
  }

  float angle = Kg * heading;

  // Select the closest useful Pixy2 CCC block (largest image Y) while
  // rejecting detections that are too small or implausibly large.
  int maxY = 0;
  Block selectedBlock;
  bool obstacleFound = false;

  for (int i = 0; i < pixy.ccc.numBlocks; i++) {
    const Block candidate = pixy.ccc.blocks[i];
    // Only trained pillar colours are valid; ignore other Pixy2 signatures.
    if ((candidate.m_signature == 1 || candidate.m_signature == 2)
        && candidate.m_y > maxY
        && candidate.m_height > PIXY_MIN_BLOCK_HEIGHT
        && candidate.m_height < PIXY_MAX_BLOCK_HEIGHT) {
      maxY = candidate.m_y;
      selectedBlock = candidate;
      obstacleFound = true;
    }
  }

  if (OBSTACLE_ROUND) {
    if (obstacleFound && millis() > obstacleRecoveryUntil) {
      setRobotState(RobotState::OBSTACLE_AVOIDANCE);
    } else if (robotState == RobotState::OBSTACLE_AVOIDANCE && !obstacleFound) {
      obstacleRecoveryUntil = millis() + OBSTACLE_RECOVERY_MS;
      setRobotState(RobotState::OBSTACLE_RECOVERY);
    } else if (robotState == RobotState::OBSTACLE_RECOVERY && millis() > obstacleRecoveryUntil) {
      setRobotState(RobotState::NORMAL_DRIVING);
    }
  }

  // In OBSTACLE_AVOIDANCE the camera contribution temporarily becomes
  // dominant. Different signatures use different target offsets so the
  // vehicle passes the obstacle on the required side.
  if (robotState == RobotState::OBSTACLE_AVOIDANCE && obstacleFound) {
    const int offset = selectedBlock.m_signature == 1
      ? PIXY_SIGNATURE_1_OFFSET
      : PIXY_SIGNATURE_2_OFFSET;

    const int cameraError = pixy.frameWidth / 2 + offset - selectedBlock.m_x;
    angle = PIXY_STEERING_GAIN * cameraError;
  }

  // Clockwise driving follows the left (outer) wall; counter-clockwise
  // driving follows the right (outer) wall.
  const Distance_Result outerDistance = isClockwise ? leftDistance : rightDistance;
  const int targetWallDistance = sectorWidth[currentSector] == 0
    ? TARGET_DISTANCE
    : sectorWidth[currentSector] / 2;
  const float dist_err = outerDistance.distance - targetWallDistance;
  float err = last_error - heading;

  const bool wallControlAllowed =
    (!OBSTACLE_ROUND && sideLock)
    || (OBSTACLE_ROUND && robotState == RobotState::NORMAL_DRIVING);

  if (wallControlAllowed
      && outerDistance.distance <= 850
      && width <= 1100
      && (sectorWidth[currentSector] == 0 || abs(sectorWidth[currentSector] - width) <= WIDTH_THRESHOLD)) {
    angle += Kp * dist_err * (isClockwise ? 1 : -1);

    if (abs(dist_err) < 50 && edge >= 12 && abs(heading) <= 5) {
      if (clockStop == 0) {
        clockStop = millis();
      } else if ((millis() - clockStop) >= 2000) {
        setRobotState(RobotState::FINISHED);
        engine.stop();
        return;
      }
    }

    if (!OBSTACLE_ROUND && abs(heading) <= 3) {
      cumulativeWidth += width;
      measurementCount++;
    }
  }

  // Derivative damping.
  if (last_error == 0) {
    last_time = millis();
    last_error = err;
  } else {
    const float dt = millis() - last_time;
    if (dt > 0) {
      err /= dt;
      angle += Kd * err;
    }
    last_time = millis();
  }

  if (abs(angle) < 1) {
    angle = 0;
  }

  const int angle_constrained = constrain(STRAIGHT_ANGLE + round(angle), MIN_ANGLE, MAX_ANGLE);
  myservo.write(angle_constrained);
}

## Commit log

2026-04-07 Initial documentation build
    [linkage.stl, middle gear_.stl, side gear.stl]
2026-04-07 Add license and tighten video docs
2026-04-07 Polish folder and sensor docs
2026-04-07 Clarify Pi camera-only and ESP32 compute roles
2026-04-08 Clarify camera and ToF architecture
2026-04-08 Tighten documentation wording
2026-04-08 Document steering and frame construction details
2026-04-08 Adapt legacy robot logic to current architecture
2026-04-08 Add steering iteration and differential notes
2026-04-08 Update README with steering notes
2026-04-08 Clarify steering arm issue in docs
2026-04-15 Add improved chassis design documentation
2026-04-15 Refine drivetrain and steering documentation
2026-04-15 Update software flow and state logic doc
2026-04-22 Add ESP32 control code and library headers
2026-04-22 Add initial ESP32 PlatformIO control project
2026-04-23 Remove README header schematic
2026-04-23 Update submission documentation package
    [Body1 (1).stl, Body2.stl, Body3.stl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]
2026-04-23 Fix steering image version mapping
2026-04-23 Fix steering image contents
2026-04-23 Bust cache for steering V3 image
2026-04-23 Add judge-facing software flow and reproducibility docs
2026-04-24 Update documentation and model assets
    [Body1 (1).stl, blokelis.stl, gear-prototype.stl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]
2026-04-24 Replace prototype evidence with previous rack robot photos
2026-04-24 Add perfboard wiring photo to README
2026-04-24 Fix mechanical and power consistency in README
2026-04-24 Emphasize custom silicone front wheels in README
2026-04-24 Correct motor rpm values in README
2026-04-24 Add front VL53L1X ToF sensor to README
2026-04-24 Fix sensor count and power budget inconsistencies in README
2026-04-24 Align parts list with final motor, sensor, and power specs
2026-04-24 Align sensor list with final ToF sensor configuration
2026-04-24 Align electronics overview with final motor, sensor, and power values
2026-04-24 Align wiring docs with final ToF sensor layout
2026-04-24 Align schemes README with final sensor layout
2026-04-24 Align schematic description with final sensor layout
2026-04-24 Correct documented motor test speeds
2026-04-24 Add plywood case design file
2026-09-23 docs: sync current WRO 2026 documentation
2026-10-01 Replace repository contents with local WRO 2026 project
    [Body1.stl, Front.stl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]
2026-10-02 docs: strengthen wiring, software flow and test evidence
2026-10-02 docs: strengthen final mechanical and sensor rationale
2026-10-02 docs: correct Pixy2 SPI and PCB power architecture
2026-10-04 docs: add final power, sensor and calibration details
2026-10-10 docs: clarify no parking and provenance of current reliability estimates
2026-10-10 fix: ignore unknown Pixy signatures and bound corner exit time
    [main.cpp]
2026-10-10 docs: align CAD inventory and describe camera, sensor and safety changes
2026-10-10 docs: tighten WRO documentation PDF for print
2026-10-12 docs: reference Makeblock 12040 motor driver and distinguish 12070 variant
2026-10-12 docs: confirm Makeblock SKU 12040 as final motor driver
2026-10-12 ci(docs): render printable PDF from final README and keep motor-driver model exact
2026-10-12 docs(pdf): synchronize printable documentation with latest README
